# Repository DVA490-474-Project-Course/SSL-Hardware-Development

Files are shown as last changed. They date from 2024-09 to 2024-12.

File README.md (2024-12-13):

# SSL-Hardware-Development

## Overview
Welcome to the SSL Robot Project repository! This project encompasses both hardware and software components essential for building and controlling an SSL robot. Our goal is to create a robust, scalable, and maintainable robot platform.

## Repository Structure
- **3D_Models**: Contains all 3D models related to the robot design.
- **Circuits**: Circuit designs for various robot components.
- **BOM**: Bill of Materials for each component.
- **Software**: Firmware and software for motor control and other functionalities.
- **Design_Documents**: Technical specifications and design decisions.
- **Meeting_Notes**: Documentation of project meetings.
- **Misc**: Miscellaneous files and references.
- **Simulations**: Simulation scripts and models.
- **Documentation**: Comprehensive project documentation and guides.

```bash
/SSL-Robot-Project
├── /3D_Models
│   ├── /CAD_Files            # All CAD files for different robot parts
│   ├── /STL_Files            # STL exports for 3D printing
│   └── /Renderings           # Renders of the 3D models
├── /Circuits
│   ├── /Motor_Control        # Motor circuit design files
│   ├── /Kicker               # Kicker circuit design files
│   ├── /Dribbler             # Dribbler circuit design files
│   └── /Sensor               # Sensor circuit design files
├── /BOM                      # Bill of Materials for different components
├── /Software
│   ├── /Motor_Control
│   │   ├── /Firmware          # Firmware code for motor controllers
│   │   │   ├── /src           # Source code files
│   │   │   ├── /include       # Header files
│   │   │   ├── /tests         # Unit and integration tests
│   │   │   └── README.md      # Firmware-specific documentation
│   │   ├── /Software_Doc      # Documentation related to motor control software
│   │   │   ├── /API_Docs      # API documentation if applicable
│   │   │   └── /User_Guides   # User manuals or setup guides
│   │   ├── /Libraries         # Any libraries or dependencies specific to motor control
│   │   └── /Examples          # Example projects or usage scenarios
│   ├── /Kicker_Control        # Similar structure for kicker control software
│   ├── /Dribbler_Control      # Similar structure for dribbler control software
│   └── /Sensor_Control        # Similar structure for sensor control software
├── /Design_Documents          # Technical specifications, design decisions
├── /Meeting_Notes             # Notes from each project meeting
├── /Misc                      # Any other miscellaneous files
├── /Simulations               # Simulation files or scripts if applicable
├── /Documentation             # General documentation for the project
│   ├── README.md              # Overview of the project
│   ├── CONTRIBUTING.md        # Guidelines for contributing
│   ├── LICENSE.md             # Licensing information
│   └── /Wiki_Links            # Links to relevant wiki pages
└── .gitignore                 # Git ignore file
```

## Getting Started

### Prerequisites
- **Hardware**: Access to the necessary hardware components as listed in the BOM.
- **Software**: Install required software dependencies (refer to [Dependencies](Software/Software_Dependencies.md) documentation).

### Setup Instructions
1. **Clone the Repository**
    ```bash
    git clone git@github.com:DVA490-474-Project-Course/SSL-Hardware-Development.git
    cd SSL-Robot-Project
    ```

2. **Setup Software Environment**
    - Navigate to the software directory:
        ```bash
        cd Software/Motor_Control
        ```
    - Follow the instructions in `README.md` to build and deploy the firmware.

3. **Accessing Documentation**
    - Visit the [Wiki](https://github.com/DVA490-474-Project-Course/SSL-Hardware-Development/wiki) for detailed guides and API documentation.

## Contributing
We welcome contributions! Please read our [CONTRIBUTING.md](Documentation/CONTRIBUTING.md) for guidelines on how to get involved.

## License
This project is licensed under the [MIT License](Documentation/LICENSE).

## Contact
For any questions or support, please open an issue or contact the project maintainers.

Pontus Svensson - psn19003@student.mdu.se

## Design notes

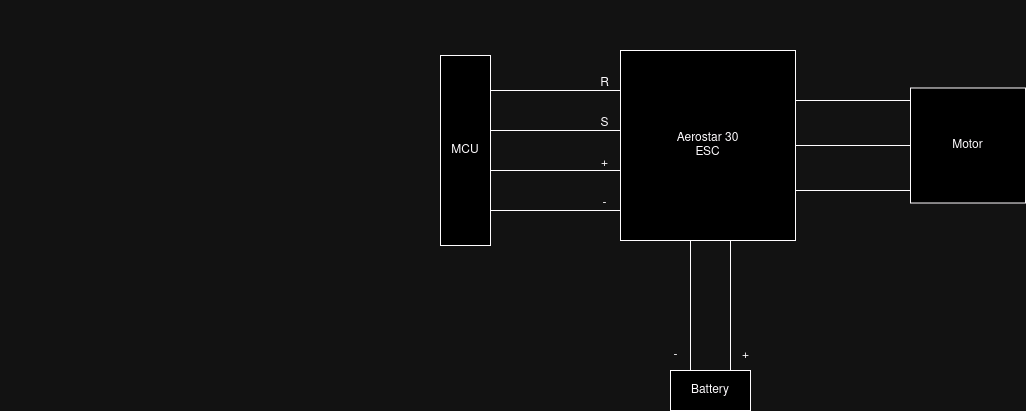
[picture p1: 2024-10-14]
Design_Documents/Dribbler/Aerostar_dribbler_diagram.png

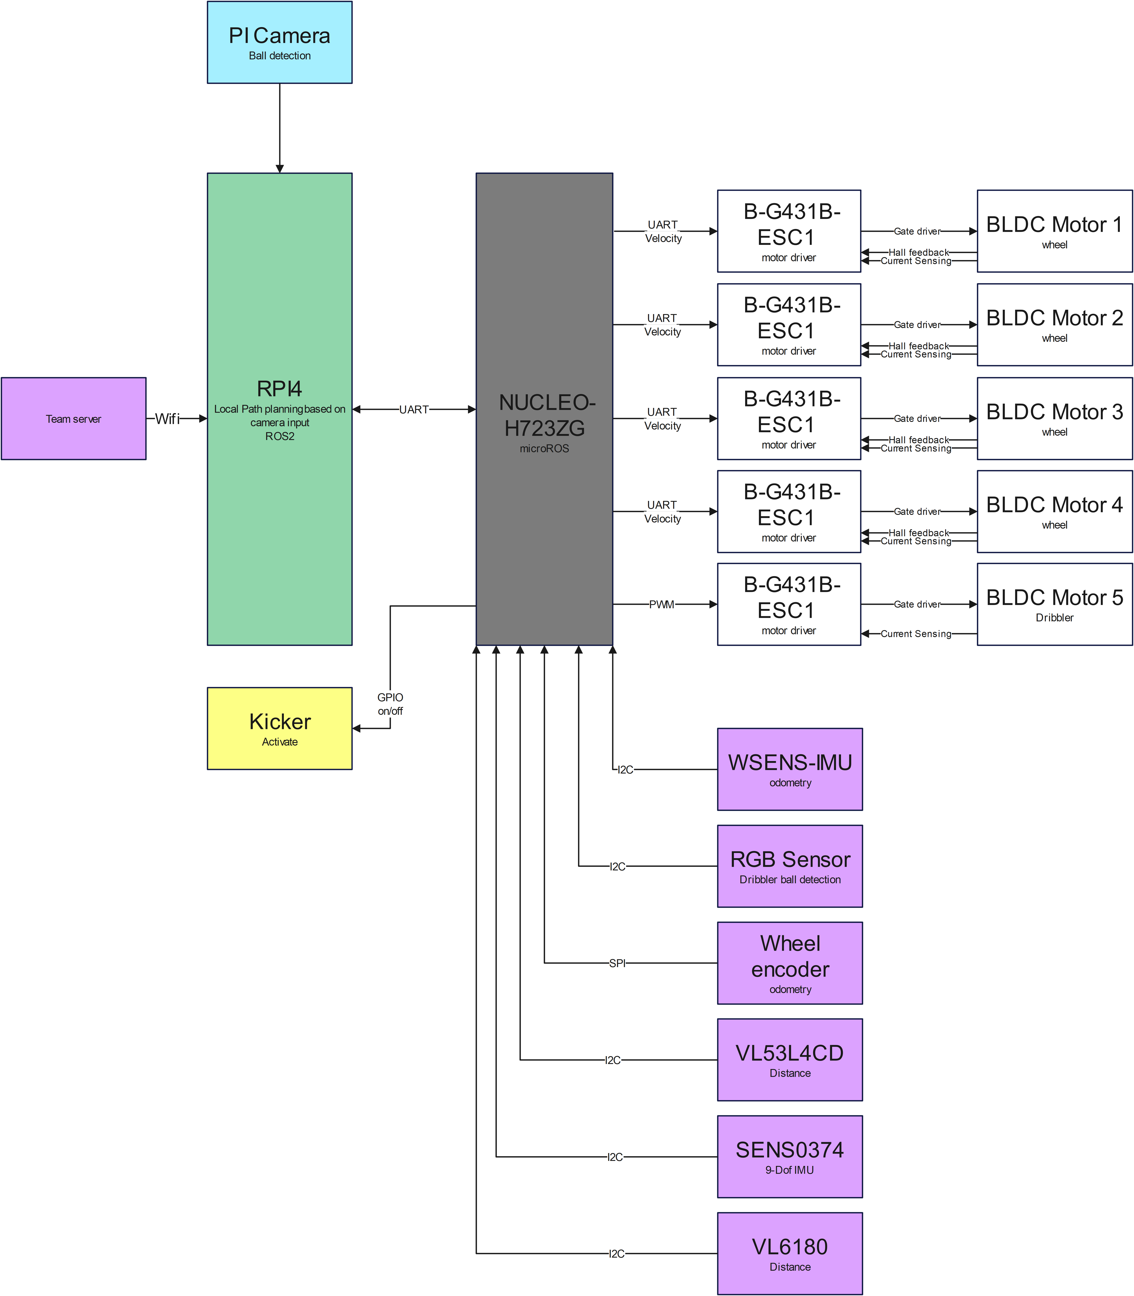
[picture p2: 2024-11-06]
Design_Documents/Architecture/Hardware_architecture.png

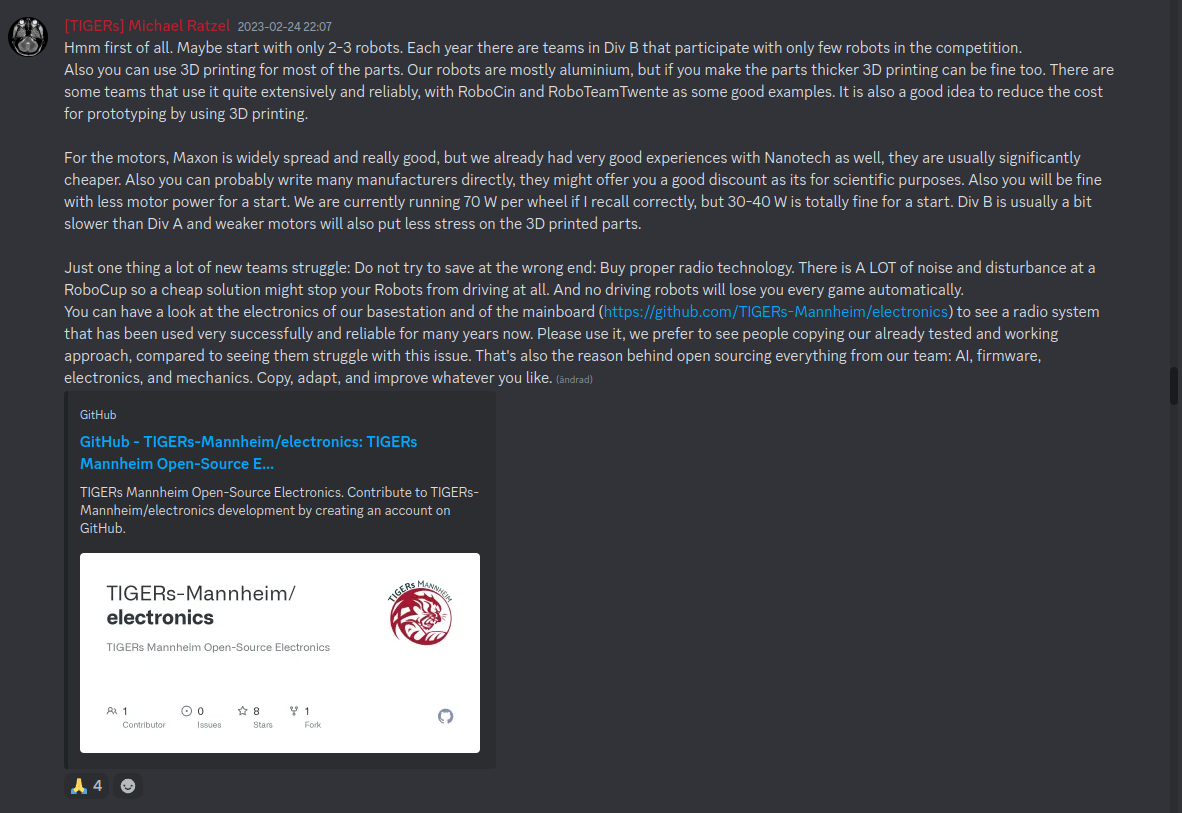
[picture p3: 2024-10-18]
Misc/knwoledge_from_tigers.png

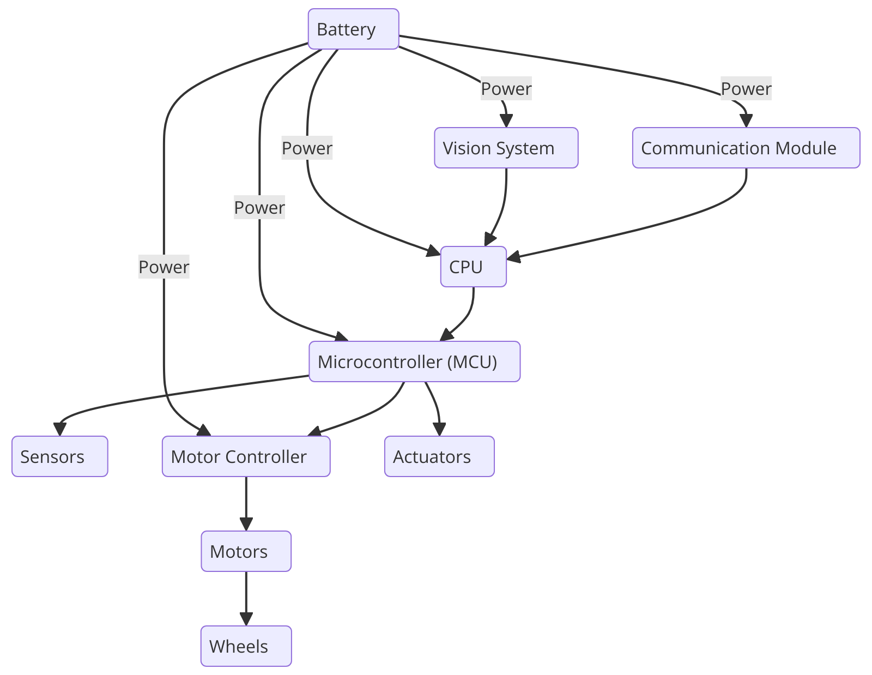
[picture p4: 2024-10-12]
Misc/diagram.png

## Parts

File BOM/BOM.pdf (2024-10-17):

BOM

Part name | Quantity
DF45L024048-A – Brushless DC motor | 4
Hobbywing FPV XRotor 3110 900KV | 1
6s 1300mAh -120C - GNB HV XT60 | 1
M3 16mm galvanized steel countersunk screw, 100 pack | 1
M3 galvanized steel locking washers, 200 pack | 1
M3 steel locking washers, 200 pack | 1
M3 stainless steel nut, 100 pack | 1
PHR-6 | 8
B6B-PH-K-S | 10
VHR-5N | 10
Bearings with flange iglidur® M250 | 200
X-RING 3.63X2.62/NBR70 | 100
SEN0374 | 1
Raspberry Pi RTC | 1
| 2
LM74500QDDFRQ1 | 2
BUK9Y8R5-80EX | 2
NUCLEO-H723ZG | 1
SX1280IMLTRT | 1
SKY66122-11 | 1
B-G431B-ESC1 | 5
Wheel hub 4mm | 4
Raspberry Pi 4 Model B/8GB | 1
Raspberry Pi Kameramodul 3 | 1
Bearings 5mm | 6
M3 threaded inserts 3mm, 50 pack | 1
APDS-9960 | 1
TOF400C-VL53L1 | 1
VL6180 TOF | 1
XT60PW-M | 1
2-post pillow block, 32mm bore | 4
B5P-VH | 10
OFFERT finns för nedanstående, se bifogad fil
OFFERT – BROADCOM AEDB-9140-A13 | 8

LT3751

Distributor

https://www.nanotec.com/eu/en/products/1786-df45l024048-a
https://www.elefun.se/p/prod.aspx?v=65193
https://www.elefun.se/p/prod.aspx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
https://www.elfa.se/sv/lasbricka-m3-stal-bossard-az-2x6x0-cll4880/p/30071831https://www.elfa.se/sv/sexkantsmutter-m3-4mm-rostfritt-stal-rnd-rnd-610-00485/p/30172720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

https://www.mouser.se/ProductDetail/Analog-Devices/LT3751IFEPBF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

https://www.mouser.se/ProductDetail/511-NUCLEO-H723ZGhttps://www.mouser.se/ProductDetail/Semtech/SX1280IMLTRT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
https://www.electrokit.com/axelnav-med-klamfaste-4mm
https://www.electrokit.com/raspberry-pi-4-model-b/8gb
https://www.electrokit.com/raspberry-pi-kameramodul-3-12mp-75https://www.electrokit.com/kullager-5mmhttps://www.electrokit.com/ganginsats-m3-x-3mm-50-packhttps://www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

https://uk.farnell.com/broadcom-limited/aedb-9140-a13/encoder-3channel-500cpr-8mm/dp/1161087

Distributor Part Number

DF45L024048-A
65193
63197
301-72-632
300-71-826
300-71-831
301-72-720
143-01-984
143-01-948
300-21-738
MFM-0103-02
2111395N70
426-SEN0374
713-103030277

584-LT3751IFE#PBF
595-LM74500QDDFRQ1
771-BUK9Y8R5-80EX

511-NUCLEO-H723ZG
947-SX1280IMLTRT
873-SKY66122-11
511-B-G431B-ESC1
41020172
41017664 - Raspberry Pi
41020240 - Raspberry Pi
41019266
41018554
41013512 – Sparkfun

XT60PW-M
RP-Sct-2151
JST (JAPAN SOLDERLESS TERMINALS) B5P-VH(LF)(SN)

BROADCOM AEDB-9140-A13

Manufacturer | Mfr Part number | Á price
| | 818.4
https://www.hobbywing.com/ | HW30418005 | 219
http://www.gaonengbattery.com/ | GNB13006S120AHV | 442
https://www.elfa.se/sv/manufacturer/rnd/man_rnd | RND 610-00397 | 21.6
https://www.bossard.com/se-sv/ | AZ 3,2X6X0,4 | 69.7
https://www.bossard.com/se-sv/ | AZ S 3,2X6X0,4 / CLL4880 S | 83.3
https://www.elfa.se/sv/manufacturer/rnd/man_rnd | RND 610-00485 | 21.85
https://www.elfa.se/sv/manufacturer/jst/man_jst | PHR-6 | 1.07
https://www.elfa.se/sv/manufacturer/jst/man_jst | B6B-PH-K-S | 5.43
https://www.elfa.se/sv/manufacturer/jst/man_jst | VHR-5N | 2.22
https://www.igusab.se/ | MFM-0103-02 | 3.34
| | 6.2
https://www.mouser.se/manufacturer/dfrobot/ | SEN0374 | 191.48
https://www.mouser.se/manufacturer/seeed-studio/ | 103030277 | 1
https://www.mouser.se/manufacturer/analog-devices/ | LT3751IFE#PBF | 147.09
https://www.mouser.se/manufacturer/texas-instruments/ | LM74500QDDFRQ1 | 16.45
https://www.mouser.se/manufacturer/nexperia/ | BUK9Y8R5-80EX | 17.94
https://www.mouser.se/manufacturer/stmicroelectronics/ | NUCLEO-H723ZG | 322.58
https://www.mouser.se/manufacturer/semtech/ | SX1280IMLTRT | 75.44
https://www.mouser.se/manufacturer/skyworks-solutions/ | SKY66122-11 | 40.48
https://www.mouser.se/manufacturer/stmicroelectronics/ | B-G431B-ESC1 | 208.96
https://www.gobilda.com/ | 1309-0016-0004 | 139
https://www.raspberrypi.com/ | | 979
https://www.raspberrypi.com/ | | 369
| | 15
| | 95
https://www.sparkfun.com/ | APDS-9960 | 199
https://www.mouser.se/manufacturer/stmicroelectronics/ | VL53L1CBV0FY/1 | 176.32
https://www.st.com/en/imaging-and-photonics-solutions/vl6180.html VL6180 | 33
https://www.tme.eu/se/katalog/p,amass_1260/ | XT60PW-M | 11.21
https://www.servocity.com/ | 1602-0032 | 172.29
https://se.farnell.com/b/jst-japan-solderless-terminals | B5P-VH(LF)(SN) | 5.21
https://uk.farnell.com/b/broadcom | AEDB-9140-A13 | 309

1 Robot Cost Lead time | Notes

3273.6 In stock
219 In stock | BLDC motor for the dribbler
442 In stock | Battery
21.6 In stock
69.7 In stock
83.3 In stock
21.85 In stock
8.56 In stock | Hall sensor connector for the motor
54.3 In stock | Hall sensor connector for the motor
22.2 In stock | Motor connectors
334 in stock | Price dependent on the amount you buy
620 in stock | Price dependent on the amount you buy
191.48 4 left in stock | 9Dof IMU
47.61 In stock

294.18 In stock
32.9 In stock | Reverse polarity protection
35.88 In stock | Mosfet used with the reverse polarity protection component

322.58 In stock
75.44 In stock | RF Transceiver Long range 2.4 GHz Wireless Transceiver
40.48 In stock | RF Front End OFDM, 863 to 928 MHz, Wi-SUN, FEM
1044.8 In stock | Datasheet
556 in stock
979 In stock | Can be substituted with Raspberry Pi 4 Model B/4GB
369 In stock | Needs to be ordered with Raspberry Pi 4 Model B/8GB or Raspberry Pi 4 Model B/4GB
90 In stock | for dribbler assembly.
95 In stock
199 In stock | Chosen by UdeA, RGB sensor
176.32 In stock | Chosen by UdeA, could not find from another seller
33 In stock | Chosen by UdeA, could not find from another seller
11.21 In stock | XT60 PCB connector
689.16 On demand, 1 month delivery time For extra support for the wheels, compatible with chosen hub.
52.1 In stock | Motor connectors
2472 In stock | Offert från farnell med studentrabatt
12977.25

BLDC motors for the wheels, compact size, light weight, contains hall sensors for encoder feedback Sensored ESC is required if these are used

Capacitor charging controller for kicker

If we do not develop our own pcb this microcontroller can be used instead of the ESP32 microcontroll-Er, ADC, communication, supports micro ros

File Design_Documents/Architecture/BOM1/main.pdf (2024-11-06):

Table 1: Main components

Component | Description | Purpose | # | ´a price (price per robot) SEK | Price in USD
DF45L024048-A (https://www.nanotec.com/fileadmin/files/Datenblaetter/BLDC/DF45/DF45L024048-A.pdf?1656012533) | Brushless direct current (BLDC) motor with inte-grated hall sensors for the wheels | Used to spin the wheels of the robot. | 4 | 830.4 (3273.60) | 74.74 (294.6)
Hobbywing FPV XRotor 3110 900KV (https://www.hobbywing.com/en/products/xrotor3110) | Brushless DC mo-tor | High revolutions per minute (RPM) motor used to con-trol the dribbler. | 1 | 175.20 (175.20) | 15.77 (15.77)
B-G431B-ESC1 (https://www.mouser.se/datasheet/2/389/b-g431b-esc1-1848063.pdf) | BLDC motor driver | Motor driver with embedded µController current sensing and hall sensing to form a closed-loop control algorithm | 5 | 208.96 (1044.8) | 18.8 (94.032)
NUCLEO-H723ZG (https://www.st.com/en/evaluation-tools/nucleo-h723zg.html) | µController | Computational power and real-time processing capabilities, sup-ports µROS | 1 | 322.58 (322.58) | 29 (29)
Raspberry Pi 4 Model B/8GB (https://datasheets.raspberrypi.com/rpi4/raspberry-pi-4-datasheet.pdf) | Single-board com-puter | Processing camera input and perform-ing local path plan-ning | 1 | 979 (979) | 88.11 (88.11)
VL53L4CD ToF (https://learn.adafruit.com/adafruit-vl53l4cd-time-of-flight-distance-sensor?view=all) | Lidar | Obstacle detection (Could not find VL53X ToF) | 2 | 176.32 (176.32) | 15.87 (15.87)
VL6180 TOF (https://www.electrokit.com/upload/product/41013/41013634/DM00112632.pdf) | Lidar | Obstacle detection | 1 | 39.62 (39.62) | 3.57 (3.57)
APDS-9960 (https://docs.broadcom.com/doc/AV02-4191EN) | RGB Sensor | Ball detection | 1 | 199 (199) | 17.91 (17.91)
SENS0374 (https://wiki.dfrobot.com/BNO055_Intelligent_9_Axis_Sensor_Module_SKU_SEN0374) | 9-Dof IMU | Acceleration, Gyro-scope, Magnetome-ter | 1 | 191 (191) | 17.19 (17.19)
6s 1300mAh -120C - GNB HV XT60 (https://www.elefun.se/p/prod.aspx?v=65193) | LiPo-battery | Used to power the robot | 1 | 351.20 (351.20) | 31.6 (31.6)
iC-PX2604 + PX01S 26-30 (https://www.ichaus.de/product/ic-px-series/#documents) | Wheel encoders | Will be used for odometry and de-termining the RPM | 4 | 224.40 (897.60) | 20.2 (80.78)
WSEN-ISDS 6 Axis IMU (https://www.we-online.com/components/products/datasheet/2536030320001.pdf) | 6-DoF IMU | Will be used for odometry of the robot | 10 | N/A | N/A
Raspberry Pi Camera-module 3 (https://www.electrokit.com/upload/product/41020/41020240/Camera_Module_3_Product_Brief.pdf) | Camera | Provide images in front of the robot to detect the ball and obstacles | 1 | 369 (369) | 33.21 (33.21)

1

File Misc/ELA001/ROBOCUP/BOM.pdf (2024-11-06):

# Bill of Materials (BOM) Explanation

Pontus Svensson / RoboCup

November 6, 2024

## Contents

1 Introduction | 3
2 BOM | 3
3 Reason for component choice | 4
4 Hardware Architecture | 6

## 1 Introduction

This document provides an explanation of the Bill of Materials (BOM) used in the project. Each component listed in the BOM is described in detail, including its purpose and other relevant specifications.

## 2 BOM

Table 1 below outlines the components used in this project along with their purpose and additional information.

Table 1: Main components

Component | Description | Purpose | # | ´a price (price per robot) SEK | Price in USD
DF45L024048-A (https://www.nanotec.com/fileadmin/files/Datenblaetter/BLDC/DF45/DF45L024048-A.pdf?1656012533) | Brushless direct current (BLDC) motor with inte-grated hall sensors for the wheels | Used to spin the wheels of the robot. | 4 | 830.4 (3273.60) | 74.74 (294.6)
Hobbywing FPV XRotor 3110 900KV (https://www.hobbywing.com/en/products/xrotor3110) | Brushless DC mo-tor | High revolutions per minute (RPM) motor used to con-trol the dribbler. | 1 | 175.20 (175.20) | 15.77 (15.77)
B-G431B-ESC1 (https://www.mouser.se/datasheet/2/389/b-g431b-esc1-1848063.pdf) | BLDC motor driver | Motor driver with embedded µController current sensing and hall sensing to form a closed-loop control algorithm | 5 | 208.96 (1044.8) | 18.8 (94.032)
NUCLEO-H723ZG (https://www.st.com/en/evaluation-tools/nucleo-h723zg.html) | µController | Computational power and real-time processing capabilities, sup-ports µROS | 1 | 322.58 (322.58) | 29 (29)
Raspberry Pi 4 Model B/8GB (https://datasheets.raspberrypi.com/rpi4/raspberry-pi-4-datasheet.pdf) | Single-board com-puter | Processing camera input and perform-ing local path plan-ning | 1 | 979 (979) | 88.11 (88.11)
VL53L4CD ToF (https://learn.adafruit.com/adafruit-vl53l4cd-time-of-flight-distance-sensor?view=all) | Lidar | Obstacle detection (Could not find VL53X ToF) | 2 | 176.32 (176.32) | 15.87 (15.87)
VL6180 TOF (https://www.electrokit.com/upload/product/41013/41013634/DM00112632.pdf) | Lidar | Obstacle detection | 1 | 39.62 (39.62) | 3.57 (3.57)
APDS-9960 (https://docs.broadcom.com/doc/AV02-4191EN) | RGB Sensor | Ball detection | 1 | 199 (199) | 17.91 (17.91)
SENS0374 (https://wiki.dfrobot.com/BNO055_Intelligent_9_Axis_Sensor_Module_SKU_SEN0374) | 9-Dof IMU | Acceleration, Gyro-scope, Magnetome-ter | 1 | 191 (191) | 17.19 (17.19)
6s 1300mAh -120C - GNB HV XT60 (https://www.elefun.se/p/prod.aspx?v=65193) | LiPo-battery | Used to power the robot | 1 | 351.20 (351.20) | 31.6 (31.6)
iC-PX2604 + PX01S 26-30 (https://www.ichaus.de/product/ic-px-series/#documents) | Wheel encoders | Will be used for odometry and de-termining the RPM | 4 | 224.40 (897.60) | 20.2 (80.78)
WSEN-ISDS 6 Axis IMU (https://www.we-online.com/components/products/datasheet/2536030320001.pdf) | 6-DoF IMU | Will be used for odometry of the robot | 10 | N/A | N/A
Raspberry Pi Camera-module 3 (https://www.electrokit.com/upload/product/41020/41020240/Camera_Module_3_Product_Brief.pdf) | Camera | Provide images in front of the robot to detect the ball and obstacles | 1 | 369 (369) | 33.21 (33.21)

## 3 Reason for component choice

### 3.1 DF45L024048-A

During competition a SSL-robot is most of the time accelerating [1]. Having a motor which can provide sufficient torque at any given speed is crucial.
The DF45L024048-A BLDC motors provides a good tradeoff between torque and RPM, with integrated hall sensors. The sensors detect the position of the rotor relative to the stator which gives the ability to control the motors using commutation. The motor controller uses the signals from the hall sensors to determine the exact timing for switching the current in the stator windings. This gives a smooth motor operation while maximizing torque output.
The size of the motor has to be taken into account. Having to large footprint on the motors would cause the kicker (solenoid) to not fit in the chassi. Using a general 5010 sensorless drone motor could be used as demonstrated by [2] but this motor would require a more sophisticated ESC which would take a lot of time to develop and manufacture. The problem with searching for 5010 drone motors is that most websites does not show the full torque graph, they primarly show the torque when the motor is already spinning at 40% throttle and above. Therefore finding a 5010 drone motor with adequate torque at low speeds is deceptively difficult.
Using hall sensors is a common method utilized by several teams and proven to be a winning concept [3][4][5][1].

### 3.2 Hobbywing FPV XRotor 3110 900KV

The requirements for the dribbler motor is that it can reach high RPM (around 10000 RPM). No feedback is implemented for the dribbler motor, due to the timeframe of the project a control algorithm will not be implemented.

### 3.3 B-G431B-ESC1

A sensorless controller requires that the BLDC motor produce a measurable back electromotive force (EMF) so the controller can determine the position of the rotor and therefore cannot provide smooth commutation at start up and low speeds. [6]
The chosen electronics speed controller (ESC) has an STSPIN32F0A system in package chip which has an integrated STM32 processor with hall sensor decoding logic and current sensing capabilities. This makes this ESC a good fit with the DF45L024048-A BLDC motor.
The STSPIN32F0A chip is a common choice for controlling BLDC motors in the SSL competitions which has been proven to be reliable and succesful [3][7].
Field-Oriented control (FOC) can be implemented on the B-G431B-ESC1. Guidance and firmware for the B-G431B-ESC1 has been received from Delft Mercurians that will make the process of implementing this streamlined.
A PID system can be implemented on the chip to allow for precise movement and rapid acceleration which is critical to make fast directions changes.
The B-G431B-ESC1 will receive a desired velocity, to use this within a PID system the RPM of each motor is required. The size and weight of the ESC does also have to be taken in consideration, the B-G431B-ESC1 has a small footprint with a relatively low weight 286g. With all the components integrated on one board will make the assembly process easier and reduce any external components e.g. hall sensing or mosfets. The programming for the integrated STM32 is done using STM32 Motor Control Software Development Kit which is a graphical programming environtment from ST.

### 3.4 NUCLEO-H723ZG Microcontroller

The NUCLEO-H723ZG is a development board based on the STM32H723ZG chip, it comes with all necessary peripheral communication UART, SPI, I2C and CAN. The STM32H723ZG features an ARM Cortex-M7 core operating at up to 480 MHz, providing good processing power for handling multiple real-time tasks required in our application. Additionally, the STM32 series is widely adopted in RoboCup competitions, including the Small Size League (SSL) [3][8][5]. This widespread use underscores its reliability and effectiveness in competititions. By using STM32H723ZG chip, previous teams implementations that is open sourced can be used for guidance when developing.
To manage the various tasks and ensure smooth operation of our robot, the control architecture will be implemeted using micro-ROS in combination with FreeRTOS on the NUCLEO-H723ZG.
FreeRTOS is a real-time operating system that provides task scheduling and resource management. Implementing FreeRTOS on the NUCLEO-H723ZG allows us to handle multiple concurrent tasks efficiently, such as sensor data processing, motor control, and communication with other system components.
By using the STM32H723ZG chip future improvements can be made, without having to replace the hardware and potentially the need to re-program/port using another framework.

### 3.5 Raspberry Pi 4 Model B/8GB

It is important to accurately detect the ball and other robots in a timely manner, therefore a Raspberry Pi camera will be used, and the input image will be processed on the Raspberry Pi 4. The Raspberry pi has been used in the SSL competitions for this purpose [9][10]. A lot of information and open sourced firmware exist.

The Raspberry Pi 4 was also chosen to be able to run the DWA path planning algorithm, due to the timeframe of this project, implementing DWA by ourself would require too much time.

### 3.6 VL53L4CD ToF Sensor

The VL53L4CD ToF (Time-of-Flight) sensor is a laser-based ranging sensor capable of measuring distances with high accuracy. It is used for obstacle detection in the robot, allowing the system to identify obstacles within close proximity. With a range of up to 1300 mm, it is especially suited for detecting obstacles that could interfere with the robot’s navigation. The sensor communicates using I2C, which simplifies integration with the existing hardware.

### 3.7 VL6180 TOF Sensor

The VL6180 TOF sensor, also a Time-of-Flight sensor, serves a similar purpose as the VL53L4CD but operates at shorter distances, making it ideal for near-field obstacle detection. It is also chosen for its compact size and I2C communication, which allows it to seamlessly interface with the microcontroller. The shorter range provides additional resolution for objects very close to the robot, further enhancing obstacle detection accuracy.

### 3.8 APDS-9960 Sensor

The APDS-9960 sensor is a versatile RGB sensor with integrated IR sensing capabilities. It is primarily used in this project for ball detection, as it can distinguish colors and detect the presence of nearby objects. This feature enables the robot to differentiate the ball from the surroundings based on color and proximity. Communication is handled via I2C, allowing for easy connection to the system’s microcontroller.

### 3.9 SENS0374 Sensor

The SENS0374, based on the Bosch BNO055 sensor, is a 9-axis absolute orientation sensor module. It integrates a triaxial accelerometer, gyroscope, and geomagnetic sensor with a 32-bit microcontroller, providing orientation data essential for stable navigation and localization. The module includes an onboard fusion algorithm that combines sensor readings to deliver absolute orientation, minimizing drift over time. The SENS0374 communicates via I2C and SPI, making it flexible for integration with the main controller. This sensor will aid in tracking the robots movement, orientation, and any external forces acting upon it, enhancing its responsiveness in dynamic environments.

### 3.10 SX1280IMLTRT + SKY66122-11

To obtain a reliable connection to the team server, the SX1280IMLTRT RF transceiver with the SKY66122-11 front-endmodule is used.
This implementation has been proven succesful by several teams [3][11].
However, to implement this, a basestation is required and due to the time limitation of this project it is not feasible to design and write firmware for our own network protocol, but these components will be added to the mainboard PCB for future iterations. The communication will instead be done using the wifi on the Raspberry Pi 4.

### 3.11 iC-PX2604 + PX01S 26-30

This wheel encoder comes as a complete module which will be easy to integrate and in combination with the NUCLEO-H723ZG the resolution of the encoder is increased.
Optical wheel encoders is commonly used by teams competing in the SSL competitions.

### 3.12 WSEN-ISDS 6 Axis IMU

The IMU chosen is supplied free of charge from W¨urth electronics. It communicates using I2C or SPI which both are available on the NUCLEO-H723ZG.

### 3.13 Raspberry Pi Camera-module 3

The Raspberry Pi camera-module 3 is chosen because of its seamless integration with the Raspberry Pi 4.
A custom made solenoid would be preferred, but due to time a generic solenoid will be used for starting car engines. Supplied by MDU.

### 3.14 PCB

As some of our components require a custom PCB, three PCBs will be designed. A mainboard, kicker-board and encoder board, the main board will host connectors for the battery, motors, sensors, NUCLEO-H723ZG and pin headers for powering the Raspberry Pi. The mainboard will also host the RF transceiver, IMU and voltage regulators.

## 4 Hardware Architecture

Figure 1 depicting the hardware architecture of the proposed robot.

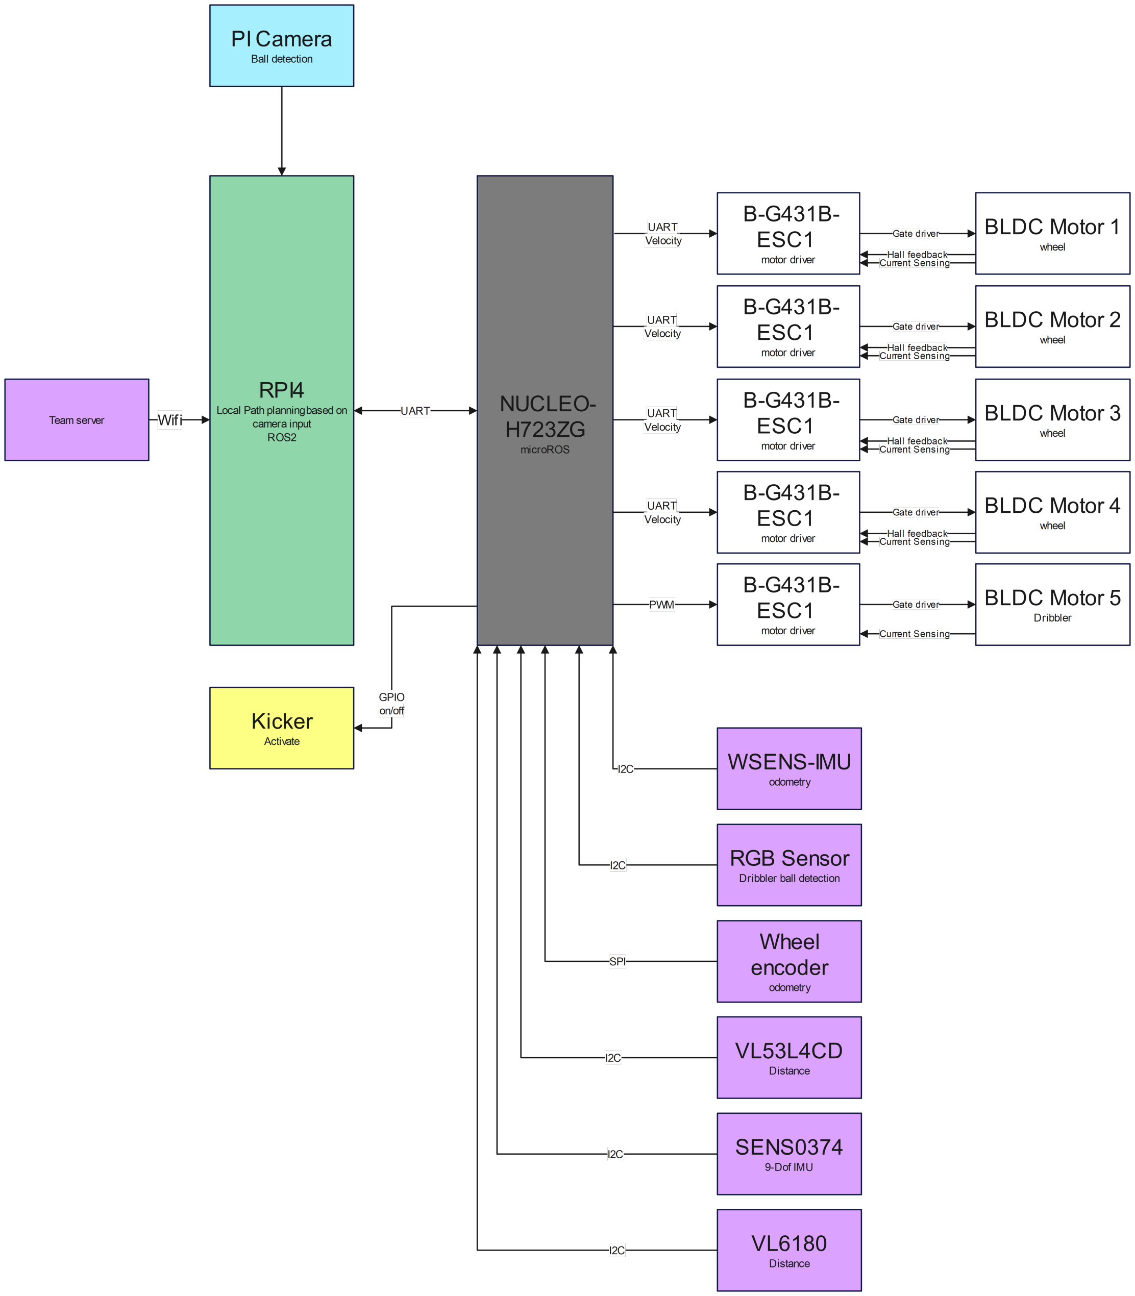
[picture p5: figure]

Figure 1: Hardware Architecture

## References

[1] A. Franca, B. Barros, C. Gomes, C. Silva, C. M. Alves, D. C. Barbosa, D. Xavier, E. Araujo, F. Pereira, L. H. Cavalcanti, M. Asfora, M. Alves, M. Paixao, M. Vasconcelos, M. Vinıcius, J. G. Melo, J. R. Silva, J. Leite, P. H. Santana, P. P. Oliveira, R. Rodrigues, T. Teobaldo, V. Dutra, V. Araujo, and E. Barros, “RobˆoCIn Small Size League Extended Team Description Paper for RoboCup 2024.”
[2] A. Veeraghanta, H. Bryant, S. Zheng, M. MacDougall, S. Guido, and L. Bontkes, “2024 Team Description Paper: The Bots.”
[3] A. Ryll and S. Jut, “Extended Team Description for RoboCup 2020.”
[4] D. R. H. Abiyev, N. Akkaya, T. Yirtici, E. Aytac, G. Burge, S. Abizada, A. Turk, and G. Say, “NEUIslanders Team Description Paper RoboCup 2022.”
[5] Y. Wu, K. Liu, J. Fan, H. Zhang, J. L. Minghe, Q. Li, and J. Li, “Compilation Error Team Description Paper for Small Size League of Robocup 2024.”
[6] A. Rowe, G. Sen Gupta, and S. Demidenko, “Instrumentation and control of a high power BLDC motor for small vehicle applications,” in 2012 IEEE International Instrumentation and Measurement Technology Conference Proceedings. Graz, Austria: IEEE, May 2012, pp. 559–564.
[7] A. Abousaleh, A. Balamurali, B. Blair, R. Cao, M. Charara, L. Chee, J. Coffin, J. Guo, W. Ha, F. Haas, T. Kong,
R. Khan, C. Lee, O. Levy, R. Nedjabat, M. Phung, A. Sidhu, D. Sturn, M. Tong, B. Vasilchikov, K. Wakaba,
N. Zareian, S. Banna, P. Zhou, and Y. B. Zhou, “2024 Team Description Paper: UBC Thunderbots.”
[8] A. Zhao, P. Yu, Z. Huang, N. Shen, J. Yang, J. Yu, Z. Chen, L. Wang, and R. Xiong, “ZJUNlict Extended Team Description Paper.”
[9] N. Ommer, A. Ryll, M. Ratzel, and M. Geiger, “Extended Team Description for RoboCup 2024.”
[10] H. Sato, N. Okamoto, A. Ito, S. Kayaki, T. Nakao, Y. Nishimura, Y. Hara, and R. Yuri, “GreenTea 2024 Team Description Paper.”
[11] H. Barreto, L. E. Horie, E. G. Frese, de Freitas, M. C. Antunes, E. Baldi, and E. H. V. Melo, “RoboIME: Igniting Innovation, Shaping the Future in RoboCup 2024.”

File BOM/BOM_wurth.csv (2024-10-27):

Order code | Quantity | Description | Link
885012007063 | 10 | WCAP-CSGP MLCCs 50 V(DC) 1nF 0805 | https://www.we-online.com/en/components/products/WCAP-CSGP-50VDC#885012007063
885012207092 | 10 | WCAP-CSGP MLCCs 50 V(DC) 10nF 0805 | https://www.we-online.com/en/components/products/WCAP-CSGP-50VDC#885012207092
885012207098 | 12 | WCAP-CSGP MLCCs 50 V(DC) 0.1uF 0805 | https://www.we-online.com/en/components/products/WCAP-CSGP-50VDC?sq=885012207098#885012207098
885012207103 | 10 | WCAP-CSGP MLCCs 50 V(DC) 1uF 0805 | https://www.we-online.com/en/components/products/WCAP-CSGP-50VDC#885012207103
885012107018 | 1 | WCAP-CSGP MLCCs 50 V(DC) 4.7uF 0805 | https://www.we-online.com/en/components/products/WCAP-CSGP-25VDC#885012107018
885012209073 | 10 | WCAP-CSGP MLCCs 50 V(DC) 10uF 1210 | https://www.we-online.com/en/components/products/WCAP-CSGP-50VDC#885012209073
865080657018 | 10 | WCAP-ASLI Aluminum Electrolytic Capacitors 220uF | https://www.we-online.com/en/components/products/WCAP-ASLI#865080657018
865060663013 | 5 | WCAP-ASLI Aluminum Electrolytic Capacitors 470uF | https://www.we-online.com/en/components/products/WCAP-ASLL#865060663013
61301621821 | 1 | Socket Header Dual 16 Pins 2.54 mm | https://www.we-online.com/en/components/products/PHD_2_54_DUAL_SOCKET_HEADER_6130XX21821#61301621821
61303021821 | 1 | Socket Header Dual 30 Pins 2.54 mm | https://www.we-online.com/en/components/products/PHD_2_54_DUAL_SOCKET_HEADER_6130XX21821#61303021821
61302021821 | 1 | Socket Header Dual 20 Pins 2.54 mm | https://www.we-online.com/en/components/products/PHD_2_54_DUAL_SOCKET_HEADER_6130XX21821#61302021821
61303421821 | 1 | Socket Header Dual 32 Pins 2.54 mm | https://www.we-online.com/en/components/products/PHD_2_54_DUAL_SOCKET_HEADER_6130XX21821#61303421821
61307221821 | 2 | Socket Header Dual 72 Pins 2.54 mm | https://www.we-online.com/en/components/products/PHD_2_54_DUAL_SOCKET_HEADER_6130XX21821?sq=61307221821
61307221121 | 2 | Pin Header Dual 72 Pins 2.54 mm | https://www.we-online.com/en/components/products/PHD_2_54_THT_DUAL_PIN_HEADER_6130XX21121
61304011121 | 1 | Pin Header Single 40 Pins 2.54 mm | https://www.we-online.com/en/components/products/PHD_2_54_THT_PIN_HEADER_6130XX11121#61304011121
61300211821 | 2 | Socket Header Single 2 Pins 2.54 mm | https://www.we-online.com/en/components/products/PHD_2_54_SOCKET_HEADER_6130XX11821#61300211821
560112120001 | 4 | Resistor 10Ohm 0805 | https://www.we-online.com/en/components/products/WRIS-RSKS?sq=560112120001#560112120001
560112120013 | 1 | Resistor 100kOhm 0805 | https://www.we-online.com/en/components/products/WRIS-RSKS#560112120013

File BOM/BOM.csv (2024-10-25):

Part name | Quantity | Distributor | Distributor Part Number | Manufacturer | Mfr Part number | Á price | 1 Robot Cost | Lead time | Notes
DF45L024048-A – Brushless DC motor | 4 | https://www.nanotec.com/eu/en/products/1786-df45l024048-a | DF45L024048-A |  |  | 818.4 | 3273.6 | In stock | BLDC motors for the wheels, compact size, light weight, contains hall sensors for encoder feedback Sensored ESC is required if these are used
Hobbywing FPV XRotor 3110 900KV | 1 | https://www.elefun.se/p/prod.aspx?v=65193 | 65193 | https://www.hobbywing.com/ | HW30418005 | 219 | 219 | In stock | BLDC motor for the dribbler
6s 1300mAh -120C - GNB HV XT60 | 1 | https://www.elefun.se/p/prod.aspx?v=63197 | 63197 | http://www.gaonengbattery.com/ | GNB13006S120AHV | 442 | 442 | In stock | Battery
M3 16mm galvanized steel countersunk screw, 100 pack | 1 | https://www.elfa.se/sv/foersaenkt-skruv-foersaenkt-huvud-torx-t10-m3-16mm-paket-med-100-delar-rnd-rnd-610-00397/p/30172632 | 301-72-632 | https://www.elfa.se/sv/manufacturer/rnd/man_rnd | RND 610-00397 | 21.6 | 21.6 | In stock
M3 galvanized steel locking washers, 200 pack | 1 | https://www.elfa.se/sv/lasbricka-m3-foerzinkat-stal-bossard-az-2x6x0/p/30071826 | 300-71-826 | https://www.bossard.com/se-sv/ | AZ 3,2X6X0,4 | 69.7 | 69.7 | In stock
M3 stainless steel nut, 100 pack | 1 | https://www.elfa.se/sv/sexkantsmutter-m3-4mm-rostfritt-stal-rnd-rnd-610-00485/p/30172720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 | 301-72-720 | https://www.elfa.se/sv/manufacturer/rnd/man_rnd | RND 610-00485 | 21.85 | 21.85 | In stock
PHR-6 | 8 | https://www.elfa.se/sv/hylskontakthus-crimpanslutning-uttag-sockel-positioner-2mm-jst-phr/p/14301984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 | 143-01-984 | https://www.elfa.se/sv/manufacturer/jst/man_jst | PHR-6 | 1.07 | 8.56 | In stock | Hall sensor connector for the motor
B6B-PH-K-S | 10 | https://www.elfa.se/sv/stiftlist-enradig-rak-6p-kontaktdon-anslutningsdon-positioner-2mm-jst-b6b-ph/p/14301948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 | 143-01-948 | https://www.elfa.se/sv/manufacturer/jst/man_jst | B6B-PH-K-S | 5.43 | 54.3 | In stock | Hall sensor connector for the motor
VHR-5N | 10 | https://www.elfa.se/sv/crimp-kontakthus-uttag-sockel-positioner-96mm-jst-vhr-5n/p/30021738 | 300-21-738 | https://www.elfa.se/sv/manufacturer/jst/man_jst | VHR-5N | 2.22 | 22.2 | In stock | Motor connectors
X-RING 3.63X2.62/NBR70 | 100 | https://webbshop.teknikprodukter.se/x-ring-3-63x2-62-nbr70-2111395n70 | 2111395N70 |  |  | 6.2 | 620 | in stock | Price dependent on the amount you buy
SENS | 1 | https://www.mouser.se/ProductDetail/DFRobot/SEN0374?qs=81r%252BiQLm7BRSXhV57X59YA%3D%3D | 426-SEN0374 | https://www.mouser.se/manufacturer/dfrobot/ | SEN0374 | 191.48 | 191.48 | 4 left in stock | 9Dof IMU
Raspberry Pi RTC | 1 | https://www.mouser.se/ProductDetail/Seeed-Studio/103030277?qs=0lSvoLzn4L8soh3xbH07wQ%3D%3D | 713-103030277 | https://www.mouser.se/manufacturer/seeed-studio/ | 103030277 | 1 | 47.61 | In stock
LT3751 | 2 | https://www.mouser.se/ProductDetail/Analog-Devices/LT3751IFEPBF?qs=hVkxg5c3xu8wGIOCrD9eEw%3D%3D | 584-LT3751IFE#PBF | https://www.mouser.se/manufacturer/analog-devices/ | LT3751IFE#PBF | 147.09 | 294.18 | In stock | Capacitor charging controller for kicker
LM74500QDDFRQ1 | 2 | https://www.mouser.se/ProductDetail/Texas-Instruments/LM74500QDDFRQ1?qs=stqOd1AaK7%252BDaolIEn1S7g%3D%3D | 595-LM74500QDDFRQ1 | https://www.mouser.se/manufacturer/texas-instruments/ | LM74500QDDFRQ1 | 16.45 | 32.9 | In stock | Reverse polarity protection
PSMN6R7-40MLDX | 2 | https://www.mouser.se/ProductDetail/Nexperia/PSMN6R7-40MLDX?qs=XeJtXLiO41T0U8eRNXd8kw%3D%3D | 771-PSMN6R7-40MLDX | https://www.mouser.se/manufacturer/nexperia/ | PSMN6R7-40MLDX | 5.77 | 11.54 | In stock | Mosfet used with the reverse polarity protection component
NUCLEO-H723ZG | 1 | https://www.mouser.se/ProductDetail/511-NUCLEO-H723ZG | 511-NUCLEO-H723ZG | https://www.mouser.se/manufacturer/stmicroelectronics/ | NUCLEO-H723ZG | 322.58 | 322.58 | In stock | If we do not develop our own pcb this microcontroller can be used instead of the ESP32 microcontroll- Er, ADC, communication, supports micro ros
SX1280IMLTRT | 1 | https://www.mouser.se/ProductDetail/Semtech/SX1280IMLTRT?qs=5aG0NVq1C4xuoq8G6ZzdxQ%3D%3D | 947-SX1280IMLTRT | https://www.mouser.se/manufacturer/semtech/ | SX1280IMLTRT | 75.44 | 75.44 | In stock | RF Transceiver Long range 2.4 GHz Wireless Transceiver
SKY66122-11 | 1 | https://www.mouser.se/ProductDetail/Skyworks-Solutions-Inc/SKY66122-11?qs=stqOd1AaK7%2F9zH4JdBCX2A%3D%3D | 873-SKY66122-11 | https://www.mouser.se/manufacturer/skyworks-solutions/ | SKY66122-11 | 40.48 | 40.48 | In stock | RF Front End OFDM, 863 to 928 MHz, Wi-SUN, FEM
B-G431B-ESC1 | 5 | https://www.mouser.se/ProductDetail/511-B-G431B-ESC1 | 511-B-G431B-ESC1 | https://www.mouser.se/manufacturer/stmicroelectronics/ | B-G431B-ESC1 | 208.96 | 1044.8 | In stock | Datasheet
VS-5EWH06FN-M3 | 4 | https://www.mouser.se/ProductDetail/Vishay-Semiconductors/VS-5EWH06FN-M3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 | 78-VS-5EWH06FN-M3 | https://www.mouser.se/manufacturer/vishaysemiconductors/ | VS-5EWH06FN-M3 | 10 | 48 | In stock | Kicker circuit
SMAJ20A | 3 | https://www.mouser.se/ProductDetail/Littelfuse/SMAJ20A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 | 576-SMAJ20A | https://www.mouser.se/manufacturer/littelfuse/ | SMAJ20A | 4 | 28 | In stock | Kicker circuit
TLP3910(C20-TP | 3 | https://www.mouser.se/ProductDetail/Toshiba/TLP3910C20-TPE?qs=TuK3vfAjtkUvVtweYOqjVw== | 757-TLP3910C20-TPE | https://www.mouser.se/manufacturer/toshiba-semiconductors/ | TLP3910(C20-TP | 36 | 46 | In stock | Kicker circuit
ECW-FD2J823KQ | 3 | https://www.mouser.se/ProductDetail/Panasonic/ECW-FD2J823KQ?qs=7EBvPakHacV3NgMNuq1u4w== | 667-ECW-FD2J823KQ | https://www.mouser.se/manufacturer/panasonicec/ | ECW-FD2J823KQ | 6 | 64 | In stock | Kicker circuit
CKG57NX7R2J474M500JH | 3 | https://www.mouser.se/ProductDetail/TDK/CKG57NX7R2J474M500JH?qs=NRhsANhppD%2BAmXDR5rVERg== | 810-CKG57NX7R2J474M | https://www.mouser.se/manufacturer/tdk/ | CKG57NX7R2J474M500JH | 46 | 58 | In stock | Kicker circuit
US1M | 3 | https://www.mouser.se/ProductDetail/Taiwan-Semiconductor/US1M?qs=tHU/lV7kTyQtvhnvJdnZJw== | 821-US1M | https://www.mouser.se/manufacturer/taiwan-semiconductor/ | US1M | 3 | 11 | In stock | Kicker circuit
FQB4N80TM | 3 | https://www.mouser.se/ProductDetail/onsemi-Fairchild/FQB4N80TM?qs=FOlmdCx%2BAA3dgdfgWff8ng== | 512-FQB4N80TM | https://www.mouser.se/manufacturer/fairchild-semiconductor/ | FQB4N80TM | 25 | 7 | In stock | Kicker circuit
IKB40N65ES5ATMA1 | 2 | https://www.mouser.se/ProductDetail/Infineon-Technologies/IKB40N65ES5ATMA1?qs=MLItCLRbWsxz7jtfFbVz2w%3D%3D | 726-IKB40N65ES5ATMA1 |  | IKB40N65ES5ATMA1 | 43.93 | 87.86 |  | Kicker Circuit
195207-231 | 1 | https://www.mouser.se/ProductDetail/Ledex/195207-231?qs=byeeYqUIh0N3hSxJ8HFfVg== | 906-195207-231 | https://www.mouser.se/manufacturer/ledex/ | 195207-231 | 426 | 19 | In stock | Kicker circuit
Wheel hub 4mm | 4 | https://www.electrokit.com/axelnav-med-klamfaste-4mm | 41020172 | https://www.gobilda.com/ | 1309-0016-0004 | 139 | 556 | in stock | Kicker circuit
Raspberry Pi 4 Model B/8GB | 1 | https://www.electrokit.com/raspberry-pi-4-model-b/8gb | 41017664 - Raspberry Pi | https://www.raspberrypi.com/ |  | 979 | 979 | In stock | Can be substituted with Raspberry Pi 4 Model B/4GB
Raspberry Pi Kameramodul 3 | 1 | https://www.electrokit.com/raspberry-pi-kameramodul-3-12mp-75 | 41020240 - Raspberry Pi | https://www.raspberrypi.com/ |  | 369 | 369 | In stock | Needs to be ordered with Raspberry Pi 4 Model B/8GB or Raspberry Pi 4 Model B/4GB
Bearings 5mm | 6 | https://www.electrokit.com/kullager-5mm | 41019266 |  |  | 15 | 90 | In stock | for dribbler assembly.
M3 threaded inserts 3mm, 50 pack | 1 | https://www.electrokit.com/ganginsats-m3-x-3mm-50-pack | 41018554 |  |  | 95 | 95 | In stock
APDS-9960 | 1 |  | 41013512 – Sparkfun | https://www.sparkfun.com/ | APDS-9960 | 199 | 199 | In stock | Chosen by UdeA, RGB sensor
TOF400C-VL53L1 | 1 | https://www.amazon.com/Teyleten-Robot-TOF400C-VL53L1X-Distance/dp/B0CLDKMGZR |  | https://www.mouser.se/manufacturer/stmicroelectronics/ | VL53L1CBV0FY/1 | 176.32 | 176.32 | In stock | Chosen by UdeA, could not find from another seller
VL6180 TOF | 1 | https://www.tinytronics.nl/en/sensors/distance/vl6180-time-of-flight-tof-distance-sensor |  | https://www.st.com/en/imaging-and-photonics-solutions/vl6180.html | VL6180 | 33 | 33 | In stock | Chosen by UdeA, could not find from another seller
XT60PW-M | 1 | https://www.tme.eu/se/details/xt60pw-m/dc-kontaktdon/amass/ | XT60PW-M | https://www.tme.eu/se/katalog/p,amass_1260/ | XT60PW-M | 11.21 | 11.21 | In stock | XT60 PCB connector
2-post pillow block, 32mm bore | 4 | https://eu.robotshop.com/products/servocity-1-side-2-post-pillow-block-32mm-bore | RP-Sct-2151 | https://www.servocity.com/ | 1602-0032 | 172.29 | 689.16 | On demand, 1 month delivery time | For extra support for the wheels, compatible with chosen hub.
B5P-VH | 10 | https://se.farnell.com/jst-japan-solderless-terminals/b5p-vh-lf-sn/connector-header-5pos-3-96mm-1row/dp/2399164 | JST (JAPAN SOLDERLESS TERMINALS) B5P-VH(LF)(SN) | https://se.farnell.com/b/jst-japan-solderless-terminals | B5P-VH(LF)(SN) | 5.21 | 52.1 | In stock | Motor connectors
OFFERT finns för nedanstående, se bifogad fil
OFFERT – BROADCOM AEDB-9140-A13 | 8 | https://uk.farnell.com/broadcom-limited/aedb-9140-a13/encoder-3channel-500cpr-8mm/dp/1161087 | BROADCOM AEDB-9140-A13 | https://uk.farnell.com/b/broadcom | AEDB-9140-A13 | 309 | 2472 | In stock | Offert från farnell med studentrabatt
 |  |  |  |  |  |  | 12904.47

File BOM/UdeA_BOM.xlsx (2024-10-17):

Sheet: Sheet1
Item |  | Description | Cantidad | Valor USD | Total USD | Factor | Total COP | Enlace | DOLAR | 4100
1 | insumo | Tarjeta sensor de ángulo de rotación | 52 | 2.4 | 126.8 | 1.8 | $936000.00 | https://didacticaselectronicas.com/index.php/view/productdetails/virtuemart_product_id/11439/virtuemart_category_id/109 | ROBOTS | 13
2 | insumo | SunnySky XS High Power X4110S Brushless Motors KV=340 | 52 | 47.0 | 2444.0 | 1.8 | $18036720.00 | https://sunnyskyusa.com/products/sunnysky-x4110s-motors
3 | insumo | Hobbywing Skywalker 60A V2 Brushless ESC BEC Speed Controller | 57 | 13.0 | 741.0 | 1.8 | $5468580.00 | https://www.aliexpress.us/item/4000092615779.html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
4 | insumo | BNO055 Accelerometer, Gyroscope, Magnetometer Sensor | 6 | 22.5 | 135.0 | 1.8 | $996300.00 | https://www.amazon.com/-/es/GY-BNO055-9-ejes-BNO055-ruptura-giroscopio/dp/B0CLJFYRX6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
5 | insumo | TransducerM AHRS 9-Axis IMU for Robotics & Autonomous Vehicles (TM151/TM171) | 6 | 45.0 | 270.0 | 1.8 | $1992600.00 | https://www.robotshop.com/products/transducerm-ahrs-9-axis-imu-for-robotics-autonomous-vehicles-tm151-tm171
6 | insumo | Sensor de distancia láser ToF. VL53L1 | 26 | 6.0 | 155.0 | 1.8 | $1144000.00 | https://www.didacticaselectronicas.com.co/shop/tof400c-vl53l1-sensor-de-distancia-laser-tof-vl53l1-21008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
7 | insumo | Sensor de distancia láser ToF. VL6180 | 13 | 3.1 | 40.2 | 1.8 | $296405.20 | https://www.didacticaselectronicas.com.co/shop/tof050c-vl6180x-sensor-de-distancia-laser-tof-vl6180-21009
8 | insumo | Kit 4 ESP32-S3-DevKitC-1-N16R8 | 4 | 27.0 | 108.0 | 1.8 | $797040.00 | https://www.amazon.com/dp/B0D3C378SJ?ref=ppx_yo2ov_dt_b_fed_asin_title
9 | insumo | Camaras sistema de vision | 4 | 80.0 | 320.0 | 1.8 | $2361600.00 | https://www.amazon.com/-/es/obturador-angular-velocidad-computadora-Tablero/dp/B0D41BSBTS
10 | equipo | SBC VIM4 8GB-RAM con NPU y kit activo de refrigeracion | 5 | 209.0 | 1045.0 | 1.8 | $7712100.00 | https://www.khadas.com/product-page/vim4
11 | insumo | Adaptador VIM4 | 5 | 30.0 | 150.0 | 1.8 | $1107000.00 | https://www.khadas.com/product-page/30w-usb-c-adapter
12 | insumo | Cable USB-C Adaptador VIM4 | 5 | 2.5 | 12.5 | 1.8 | $92250.00 | https://www.khadas.com/product-page/usb-c-cable-male-to-male
13 | insumo | New M2X Extension VIM4 | 5 | 8.0 | 40.0 | 1.8 | $295200.00 | https://www.khadas.com/product-page/new-m2x-extension
14 | insumo | SSD para VIM4 | 5 | 70.0 | 350.0 | 1.8 | $2583000.00 | https://www.amazon.com/-/es/velocidades-almacenamiento-actualizado-computadora-MZ-V9E1T0B/dp/B0CRCC9863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
15 | insumo | Tripodes para camaras | 4 | 29.0 | 116.0 | 1.8 | $856080.00 | https://www.amazon.com/-/es/Tr%C3%ADpodes-grabaci%C3%B3n-resistente-profesionales-compatibles/dp/B0B1HJ2YSH
16 | insumo | Turnigy nano-tech 1550mah 6S 65~130C Lipo Pack | 12 | 20.0 | 240.0 | 1.8 | $1771200.00 | https://hobbyking.com/en_us/turnigy-nano-tech-1550mah-6s-65-130c-lipo-pack-450l-heli.html
17 | insumo | Cable siliconado 18 AWG negro 5 metros | 12 | 2.4 | 28.9 | 1.8 | $213429.60 | https://es.aliexpress.com/item/1005001454777401.html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
18 | insumo | Cable siliconado 18 AWG rojo 5 metros | 12 | 2.4 | 28.9 | 1.8 | $213429.60 | https://es.aliexpress.com/item/1005001454777401.html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
19 | insumo | Cable siliconado 14 AWG negro 5 metros | 6 | 5.1 | 30.6 | 1.8 | $225828.00 | https://es.aliexpress.com/item/1005001454777401.html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
20 | insumo | Cable siliconado 14 AWG rojo 5 metros | 6 | 5.1 | 30.6 | 1.8 | $225828.00 | https://es.aliexpress.com/item/1005001454777401.html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
21 | insumo | Cable siliconado 10 AWG negro 5 metros | 2 | 15.5 | 31.0 | 1.8 | $228780.00 | https://es.aliexpress.com/item/1005001454777401.html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
22 | insumo | Cable siliconado 10 AWG rojo 5 metros | 2 | 15.5 | 31.0 | 1.8 | $228780.00 | https://es.aliexpress.com/item/1005001454777401.html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
23 | insumo | Tornillos Phillips de cabeza redonda roscada métricos, tuercas y arandelas (W SET) | 5 | 31.58 | 157.9 | 1.8 | $1165302.00 | https://es.aliexpress.com/item/1005006809717413.html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
24 | insumo | Filamento tipo ASA 1.75mm negro Kg | 6 | 30 | 180.0 | 1.8 | $1328400.00 | https://www.amazon.com/Polymaker-Filament-Resistant-Weather-Cardboard/dp/B09DKPYYBP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
25 | insumo | Filamento tioo PA6-CF 1.75mm negro 500g | 4 | 40 | 160.0 | 1.8 | $1180800.00 | https://www.amazon.com/Polymaker-Fiberon-PA6-CF-Filamento-filamento/dp/B0D4QDTHPQ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
26 | insumo | Filamento Polymaker TPU95-HF negro 1 Kg | 3 | 50 | 150.0 | 1.8 | $1107000.00 | https://www.amazon.com/Polymaker-Filamento-filamento-poliuretano-termopl%C3%A1stico/dp/B09KLGL459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
27 | insumo | ANYCUBIC ABS-Like Resin Pro 2 Gris x 4Kg | 2 | 67 | 134.0 | 1.8 | $988920.00 | https://www.amazon.com/impresora-resistencia-precisi%C3%B3n-compatibilidad-impresoras/dp/B0CPV7DB1M
28 | insumo | ANYCUBIC ABS-Like Resin Pro 2 Negra x 2kg | 2 | 40 | 80.0 | 1.8 | $590400.00 | https://www.amazon.com/impresora-resistencia-precisi%C3%B3n-compatibilidad-impresoras/dp/B0CPV7DB1M
29 | insumo | ANYCUBIC ABS-Like Resin Pro 2 Blanca x 2kg | 2 | 40 | 80.0 | 1.8 | $590400.00 | https://www.amazon.com/impresora-resistencia-precisi%C3%B3n-compatibilidad-impresoras/dp/B0CPV7DB1M
30 | otros | Grama sintetica 2x5mts | 8 | 54.2 | 433.6 | 1.8 | $3200000.00 | https://www.homecenter.com.co/homecenter-co/product/448419/pasto-grama-sintetica-2x5mt-espesor-10mm-verde/448419/
31 | insumo | 10m Termoencogible negro de 2mm | 2 | 1.9 | 3.7 | 1.8 | $27601.20 | https://es.aliexpress.com/item/1005007492115218.html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
32 | insumo | 10m Termoencogible rojo de 2mm | 2 | 1.9 | 3.8 | 1.8 | $27748.80 | https://es.aliexpress.com/item/1005007489518944.html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
33 | insumo | 10m Termoencogible negro de 4mm | 2 | 2.5 | 5.0 | 1.8 | $36900.00 | https://es.aliexpress.com/item/1005007492115218.html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
34 | insumo | 10m Termoencogible rojo de 4mm | 2 | 2.5 | 5.1 | 1.8 | $37342.80 | https://es.aliexpress.com/item/1005007489518944.html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
35 | insumo | Conversor DC-DC salida @5V 1.6A | 26 | 0.7 | 18.3 | 1.8 | $135200.00 | https://www.didacticaselectronicas.com/~didactic/index.php/view/productdetails/virtuemart_product_id/12027/virtuemart_category_id/837
36 | insumo | Conversor DC-DC salida@ 9V 1.1A | 26 | 0.7 | 18.3 | 1.8 | $135200.00 | https://www.didacticaselectronicas.com/~didactic/index.php/view/productdetails/virtuemart_product_id/12028/virtuemart_category_id/839
37 | insumo | Conversor DC-DC salida @ 12V 0.8A | 26 | 0.7 | 18.3 | 1.8 | $135200.00 | https://www.didacticaselectronicas.com/~didactic/index.php/view/productdetails/virtuemart_product_id/12029/virtuemart_category_id/840
38 | insumo | Conversor DC-DC salida @ 3.3V 1.8A | 26 | 0.7 | 18.3 | 1.8 | $135200.00 | https://www.didacticaselectronicas.com/~didactic/index.php/view/productdetails/virtuemart_product_id/12026/virtuemart_category_id/838
39 | insumo | 10 pairs (male-female) Bullet connectors 3.5mm | 30 | 1.1 | 33.0 | 1.8 | $243540.00 | https://es.aliexpress.com/item/1005006400659486.html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
40 | insumo | 10 pairs (male-female) Bullet connectors 4mm | 20 | 1.6 | 32.0 | 1.8 | $236160.00 | https://es.aliexpress.com/item/1005006400659486.html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
41 | insumo | 50 pairs (male-female) connector XT90 | 1 | 55.0 | 55.0 | 1.8 | $405900.00 | https://es.aliexpress.com/item/1005003614260098.html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
42 | insumo | 50 pairs (male-female) connector XT60 | 1 | 15.0 | 15.0 | 1.8 | $110700.00 | https://es.aliexpress.com/item/1005006860943414.html?scm_id=1007.40000.327270.0&scm-url=1007.40000.327270.0
43 | insumo | Extensión eléctrica10m | 5 | 4.1 | 20.3 | 1.8 | $150000.00 | https://www.didacticaselectronicas.com.co/shop/wj-c01-10m-extension-electrica-10m-3-tomas-naranja-2x14-19340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
44 | insumo | Multitoma 6 salidas 3m | 5 | 12.2 | 61.0 | 1.8 | $450000.00 | https://www.homecenter.com.co/homecenter-co/product/224676/multitoma-6-salidas-3m/224676/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
45 | insumo | Enrutador Wi-Fi 6 AX3000, Internet de doble banda | 1 | 120.0 | 120.0 | 1.8 | $885600.00 | https://www.amazon.com/TP-Link-WiFi-AX3000-Smart-Router/dp/B0BTD7V93F?adgrpid=81699018167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
46 | otros | Mesa plegable | 2 | 24.4 | 48.8 | 1.8 | $360000.00 | https://www.homecenter.com.co/homecenter-co/product/317175/mesa-plegable-metal-polietileno-blanco-180x75x74-cm/317175/
47 | otros | Silla Para Camping Plegable Sin Brazos color negro | 4 | 6.8 | 27.1 | 1.8 | $200000.00 | https://www.homecenter.com.co/homecenter-co/product/896589/silla-para-camping-plegable-sin-brazos-textil-multicolor/896589/
49 | insumo | Motor dribbling ChiHai Motor CHB-BLDC4260 DC24V 8000RPM 42mm Package A | 7 | 17.1 | 120.0 | 1.8 | $885969.00 | https://es.aliexpress.com/item/4000848454154.html?mp=1
50 | insumo | Placa High Speed Steel 4x20x200 mm | 14 | 6.0 | 84.0 | 1.8 | $619920.00 | https://es.aliexpress.com/item/1005002836006885.html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
51 | insumo | Placa de Alumino 6061 de 4x20x200mm | 14 | 1.0 | 14.0 | 1.8 | $103320.00 | https://es.aliexpress.com/item/1005006560298814.html?utparam-url=scene%3Asearch%7Cquery_from%3A
52 | insumo | Emtel 24 AWG - 1 lb (805 feet) 99.9% Pure Copper Wire, Enameled Magnetic Wire for Motor, Transformer, Magnetic Coil, & Electroculture Gardening, Winding Magnet Wire - 220°C (428°F) Thermal Class | 2 | 25.0 | 50.0 | 1.8 | $369000.00 | https://www.amazon.com/Emtel-24-AWG-transformador-electrocultural/dp/B08N6LY3JL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
53 | insumo | Resorte de tension 30mm largo y 6mm de diametro | 40 | 1.2 | 50.0 | 1.8 | $369000.00 | https://es.aliexpress.com/item/1005006529073133.html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
54 | insumo | Resorte de tension 40mm largo y 12mm de diametro | 40 | 1.6 | 62.0 | 1.8 | $457560.00 | https://es.aliexpress.com/item/1005006529073133.html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
55 | insumo | Resorte de tension 30mm largo y 4mm de diametro | 40 | 1.3 | 53.6 | 1.8 | $395568.00 | https://es.aliexpress.com/item/1005006529073133.html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
56 | insumo | 35KG 360 Degree Continuous Rotation Servo Digital Coreless 500μs-2500μs | 7 | 29.0 | 203.0 | 1.8 | $1498140.00 | https://www.amazon.com/Wishiot-TD-8135MG-Digital-Waterproof-500%CE%BCs-2500%CE%BCs/dp/B08JCVLSCK
57 | insumo | 1500μs/ 330hz 360 Continuous Rotation SPT5525LV-360 25KG Digital Servo | 14 | 6.0 | 84.0 | 1.8 | $619920.00 | https://www.amazon.com/Oumefar-Continuous-Rotation-SPT5525LV-360-Sensitivity/dp/B0BK9K425B
58 | insumo | Sensor de color RGB y de gestos, APDS9960 | 20 | 2.1 | 42.3 | 1.8 | $311994.20 | https://www.didacticaselectronicas.com.co/shop/gy-apds9960-sensor-de-color-rgb-y-de-gestos-apds9960-7021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
59 | otros | Organizador modular plástico 83x113x203mm | 64 | 2.2 | 140.3 | 1.8 | $1035776.00 | https://www.didacticaselectronicas.com.co/shop/om03caz-organizador-modular-plastico-83x113x203mm-21468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
60 | otros | Tela de Fieltro (Paño Lency) ancho 150 centimetros | 94 | 3.4 | 318.4 | 1.8 | $2350000.00 | https://casatextil.com.co/products/pano-lency-por-metros
61 | insumo | Molex 0530470310 | 180 | 0.163 | 29.4 | 1.8 | $216701.89 | https://www.digikey.com/en/products/detail/molex/0530470310/242854
62 | insumo | Molex 0510210300 | 180 | 0.118 | 21.2 | 1.8 | $156751.20 | https://www.digikey.com/en/products/detail/molex/0510210300/242843
63 | insumo | Molex 0530470410 | 55 | 0.275 | 15.1 | 1.8 | $111622.50 | https://www.digikey.com/en/products/detail/molex/0530470410/242855
64 | insumo | Molex 0510210400 | 55 | 0.198 | 10.9 | 1.8 | $80368.20 | https://www.digikey.com/en/products/detail/molex/0510210400/242844
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

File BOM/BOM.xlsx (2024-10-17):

Powertrain and Electronics
Ranking | Part name | Quantity | Distributor | Distributor Part Number | Manufacturer | Mfr Part number | Á price | Estimated cost | Lead time | Notes
Motor Wheel
1 | DF45L024048-A – Brushless DC motor | 4 | Nanotec (https://www.nanotec.com/eu/en/products/1786-df45l024048-a) | DF45L024048-A |  |  | 818.40 | 3273.60 | In stock | BLDC motors for the wheels, compact size, light weight, contains hall sensors for encoder feedback Sensored ESC is required if these are used
UdeA | MN5208 Navigator Type UAV Multi-Motor KV340 | 4 | T-motor (https://store.tmotor.com/product/mn5208-motor-navigator-type.html) | MN5208 |  |  | 1027.32 | 4109.28 | In stock | Motors similar to the one UdeA will use. Terrible torque at low speed, international shipping. Expensive compared to the DF45L024048-A
2 | Turnigy Multistar 4225-610Kv 16Pole Multi-Rotor Outrunner | 4 | HobbyKing (https://hobbyking.com/en_us/turnigy-multistar-4225-610kv-16pole-multi-rotor-outrunner.html) | 9392000008 |  |  | 297.00 | 1188.00 | In stock | Wheel BLDC Small form factor + low weight 86g Balanced RPM/V (610kV): Good tradeoff between speed and torque It provides good torque at low speeds which is needed for fast acceleration 16 poles, which gives pretty good control
3 | T-Motor MT2814 400 kv | 4 | RCflight (https://www.rcflight.se/visaprodukt.aspx?id=2951&p=t-motor-mt2814-400-kv) | MT2814-400KV | Tiger motors (https://uav-en.tmotor.com/) |  | 215.40 | 861.60 | In stock | Wheel BLDC, last batch
4 | Surpass Hobby Rocket 4114 400KV Quad Motor BL | 4 | elefun (https://www.elefun.se/p/prod.aspx?v=54896) | 54896 |  |  | 268.80 | 1075.20 | In stock | Wheel BLDC
Motor Dribbler
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

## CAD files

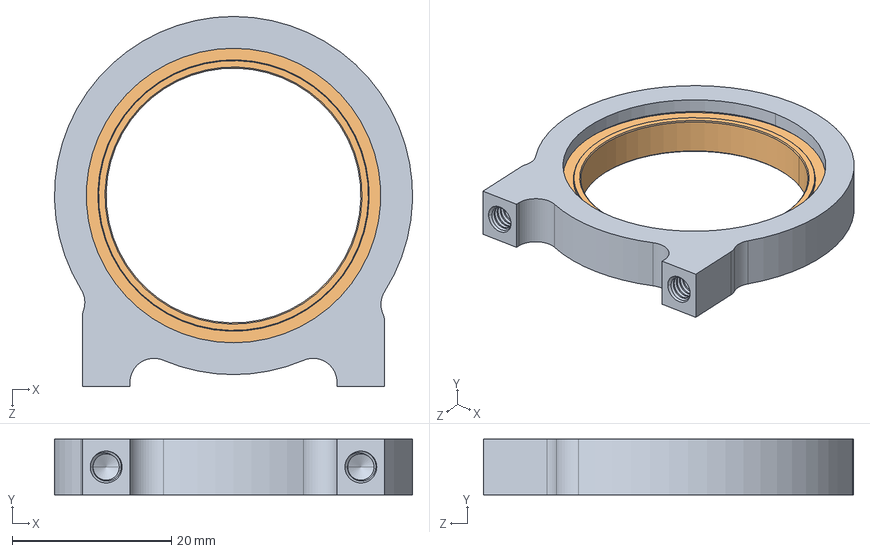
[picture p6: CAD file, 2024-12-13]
3D_Models/CAD_Files/Purchased_parts/1602-0032-0032 assembly.STEP
45.0 x 7.00 x 46.5 mm

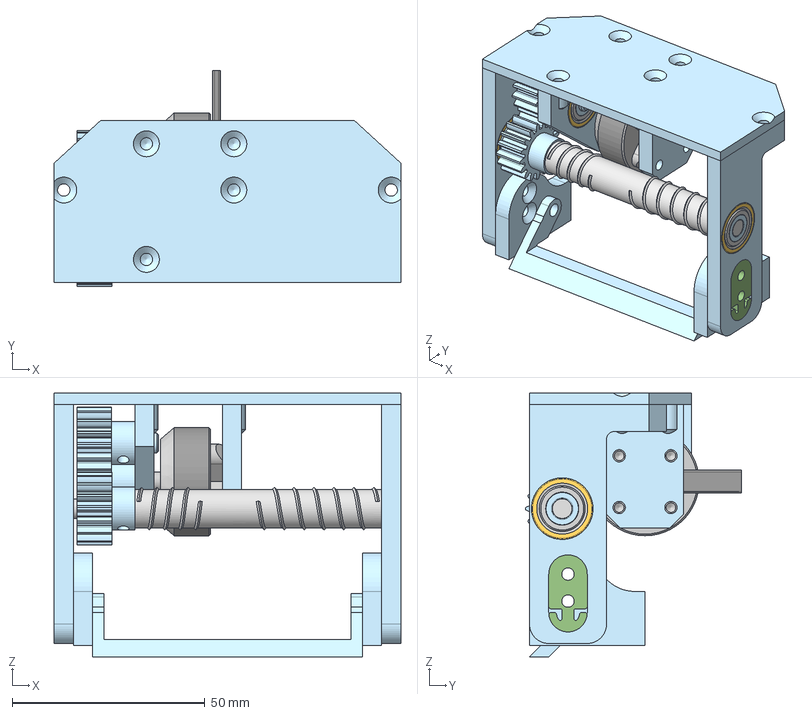
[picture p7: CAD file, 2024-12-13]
3D_Models/CAD_Files/step/Dribbler_Assembly.step
90.1 x 56.0 x 68.5 mm
Dribbler_mount x 2
Catch_bar _v3
dribbler_dampener x 2
Roller
Spur 1M 17T x 3
skf_bearing_625-z_2_1 x 16
pin_3dprint
Dribbler_bearing_holder
dribbler_motor

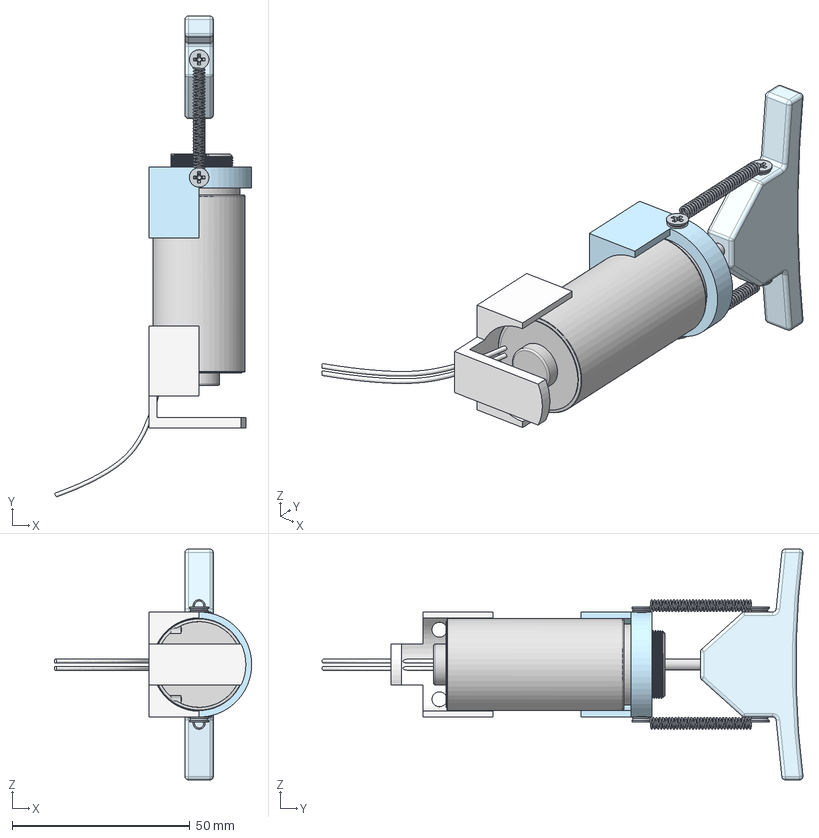
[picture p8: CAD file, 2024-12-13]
3D_Models/CAD_Files/step/Kicker_Assembly.step
55.6 x 135.4 x 65.0 mm
PH Countersunk flat head screw M3x0.5 x 6 x 6

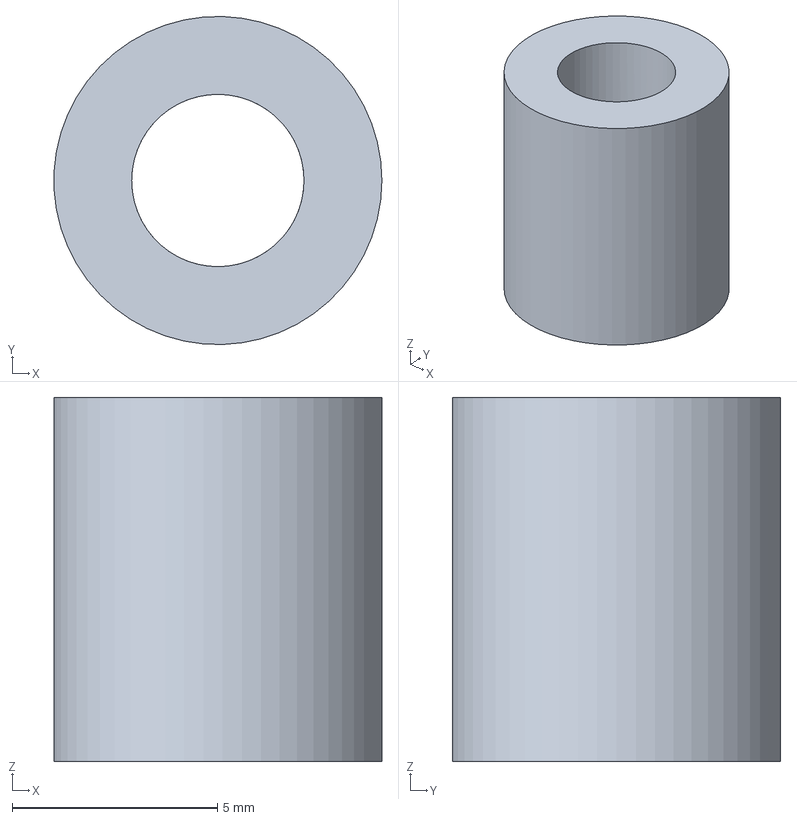
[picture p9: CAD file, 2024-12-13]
3D_Models/CAD_Files/step/offset_mainboard.step
7.99 x 8.00 x 8.88 mm

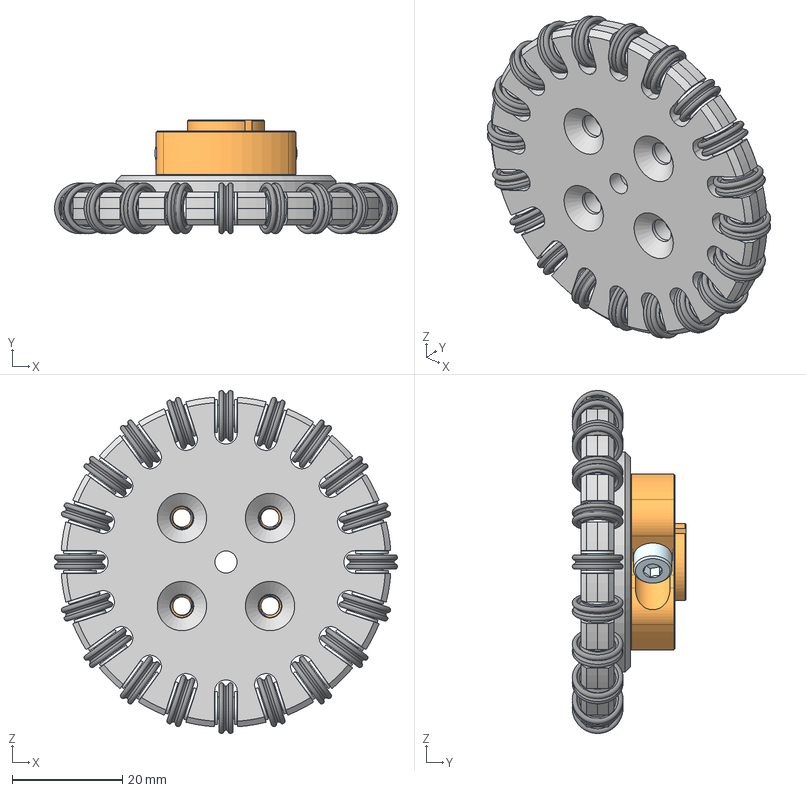
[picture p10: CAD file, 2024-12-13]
3D_Models/CAD_Files/step/Wheel_assembly.step
62.3 x 20.6 x 62.3 mm
Wheel x 2
x-ring x 20
TPE_bearing x 20
nylon_washer x 40
Parallel pin 2.5 x 8 x 20
Wheel_standoff
2800-0004-0014_90128A207 x 2

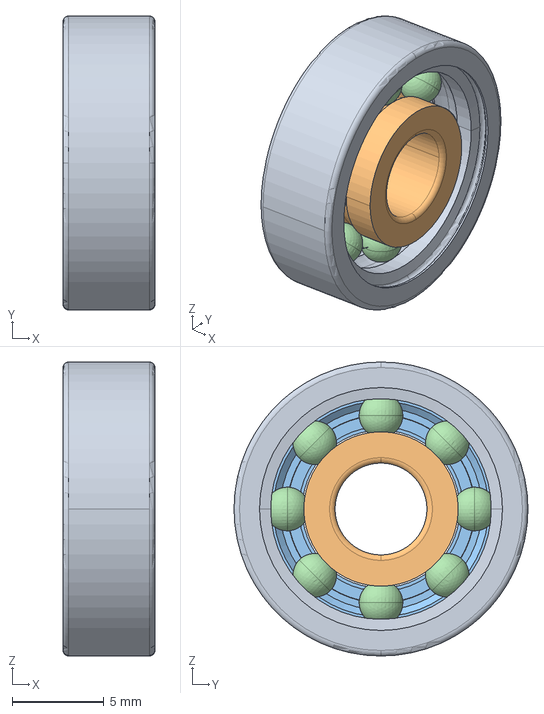
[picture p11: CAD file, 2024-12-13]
3D_Models/CAD_Files/Purchased_parts/skf_bearing_625-z_2.stp
5.00 x 16.0 x 16.0 mm

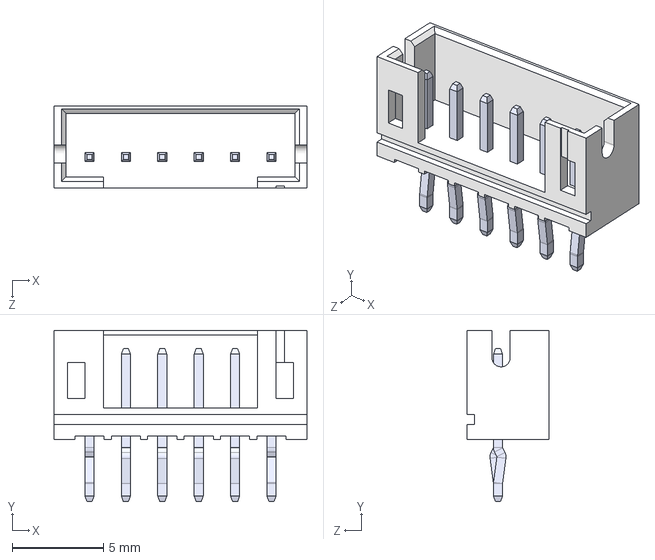
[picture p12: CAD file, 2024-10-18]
Circuits/Components/B6B-PH-K-S/B6B-PH-K-S--3DModel-STEP-56544.STEP
13.9 x 9.40 x 4.50 mm
pin x 6

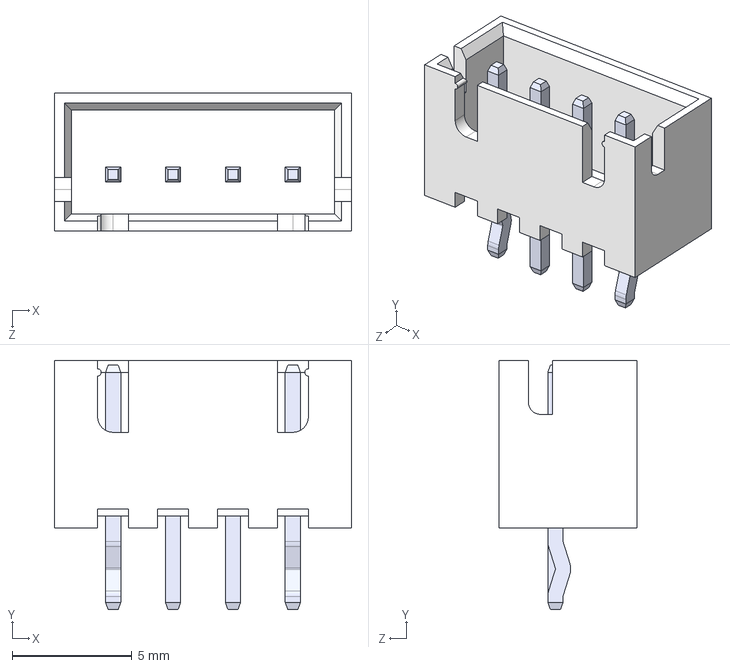
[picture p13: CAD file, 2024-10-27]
Circuits/Components/JST-XH 4A 2.54 mm pitch/B4B-XH-A--3DModel-STEP-56544.STEP
12.4 x 10.4 x 5.75 mm

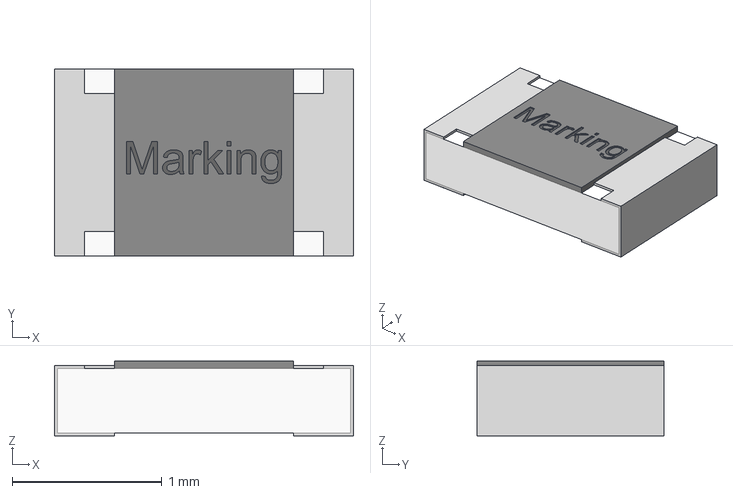
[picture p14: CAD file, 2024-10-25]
Circuits/Components/WE_560112120004_Libraries/IGS_WRIS-RSKS_0805 (rev1).igs
2.00 x 1.25 x 0.5 mm

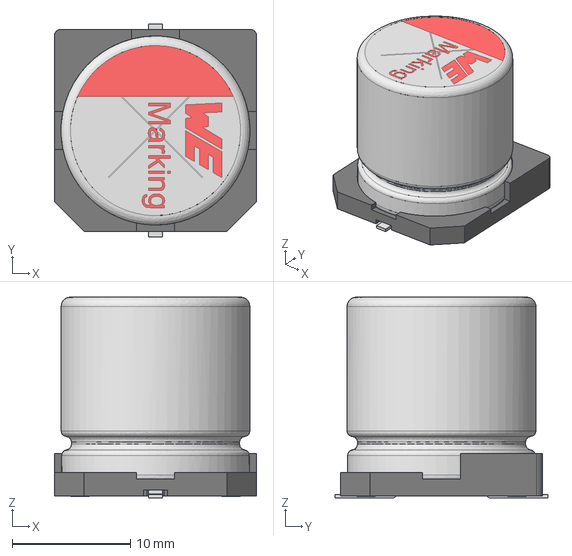
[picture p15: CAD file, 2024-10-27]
Circuits/Components/WE_865060663013_Libraries/IGS_WCAP-ASLL_16x17x6 (rev1).igs
17.1 x 18.0 x 17.0 mm

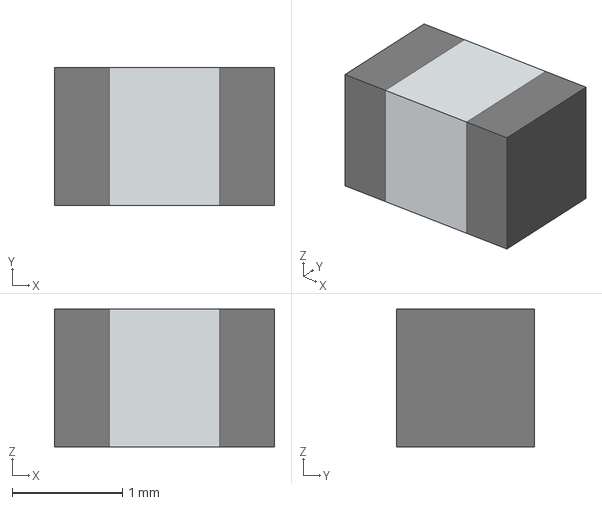
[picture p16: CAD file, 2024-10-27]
Circuits/Components/WE_885012107006_Libraries/IGS_MLCC_WACP-CSGP_0805 (rev1).igs
2.00 x 1.25 x 1.25 mm

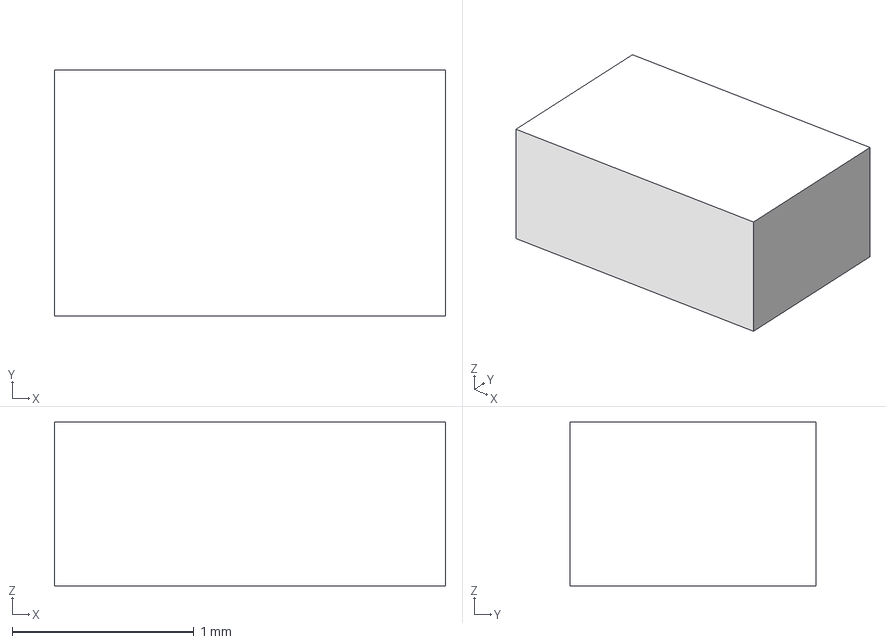
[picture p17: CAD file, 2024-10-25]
Circuits/Components/WE_885012207098_Libraries/IGS_WCAP-CSGP_0805_ 2.0x1.25x0.8x0 (rev1).igs
2.15 x 1.35 x 0.9 mm

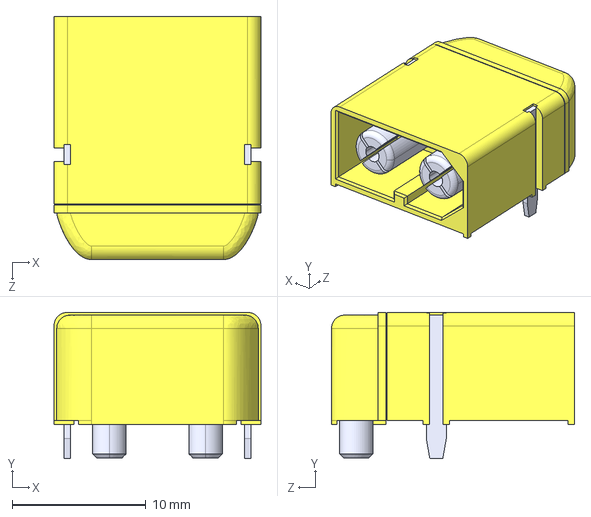
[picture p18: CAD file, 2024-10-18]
Circuits/Components/XT60PW-M/XT60PW-M--3DModel-STEP-269445.STEP
15.5 x 11.0 x 18.2 mm

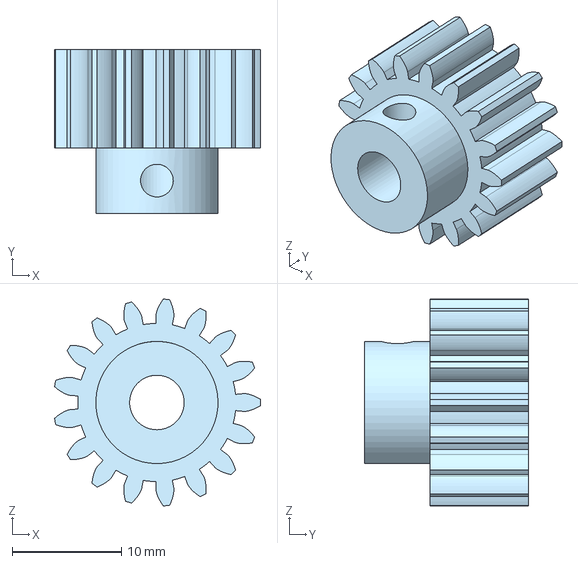
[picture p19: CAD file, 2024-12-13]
3D_Models/CAD_Files/Purchased_parts/traxxas_6490x_17t_m1_pinion.step
18.9 x 15.0 x 19.0 mm

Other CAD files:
Circuits/Mainboard/Mainboard/Unnamed-Mainboard.obj
Circuits/Mainboard/Mainboard/Mainboard.step
Circuits/Motor_Driver_carrier_board/Motor_Driver_carrier_board.step
3D_Models/CAD_Files/step/Encoder_disk.step
3D_Models/CAD_Files/Purchased_parts/195207-228.stp
3D_Models/CAD_Files/Purchased_parts/DF45L024048-A.stp
3D_Models/CAD_Files/step/Base_plate.step
3D_Models/CAD_Files/step/Battery.step
3D_Models/CAD_Files/step/Battery_mount_bottom.step
3D_Models/CAD_Files/step/Battery_mount_top.step
3D_Models/CAD_Files/step/Bearing-Oring.step
3D_Models/CAD_Files/step/Catch_bar.step
3D_Models/CAD_Files/step/Dribbler_bearing_holder.step
3D_Models/CAD_Files/step/Dribbler_dampener.step
3D_Models/CAD_Files/step/Dribbler_mount_left.step
3D_Models/CAD_Files/step/Dribbler_mount_right.step
3D_Models/CAD_Files/step/Encoder_backing.step
3D_Models/CAD_Files/step/Encoder_disk_mount.step
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

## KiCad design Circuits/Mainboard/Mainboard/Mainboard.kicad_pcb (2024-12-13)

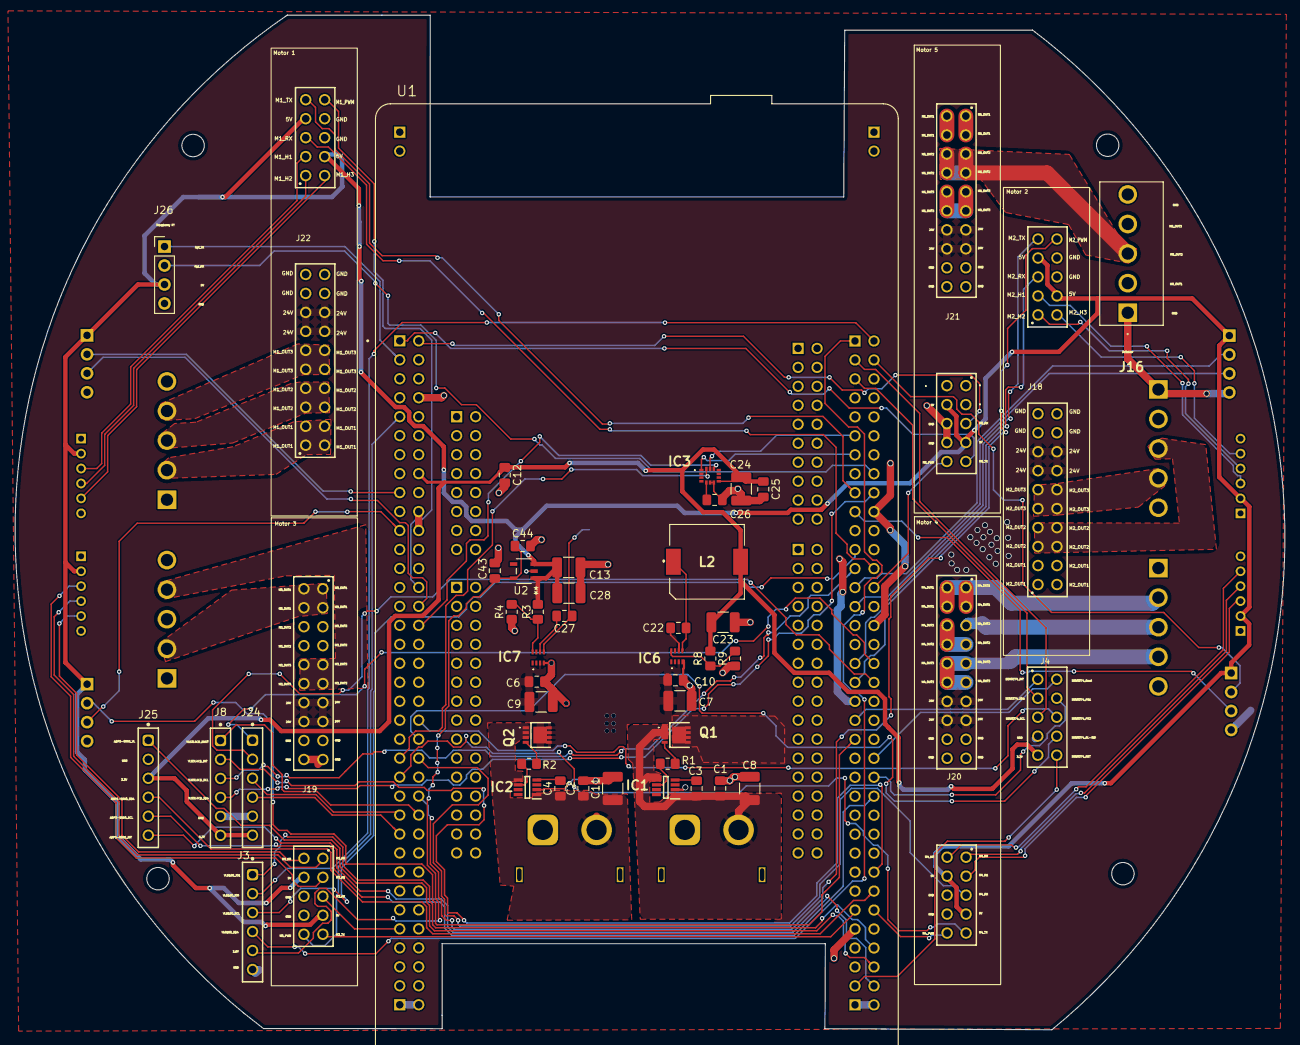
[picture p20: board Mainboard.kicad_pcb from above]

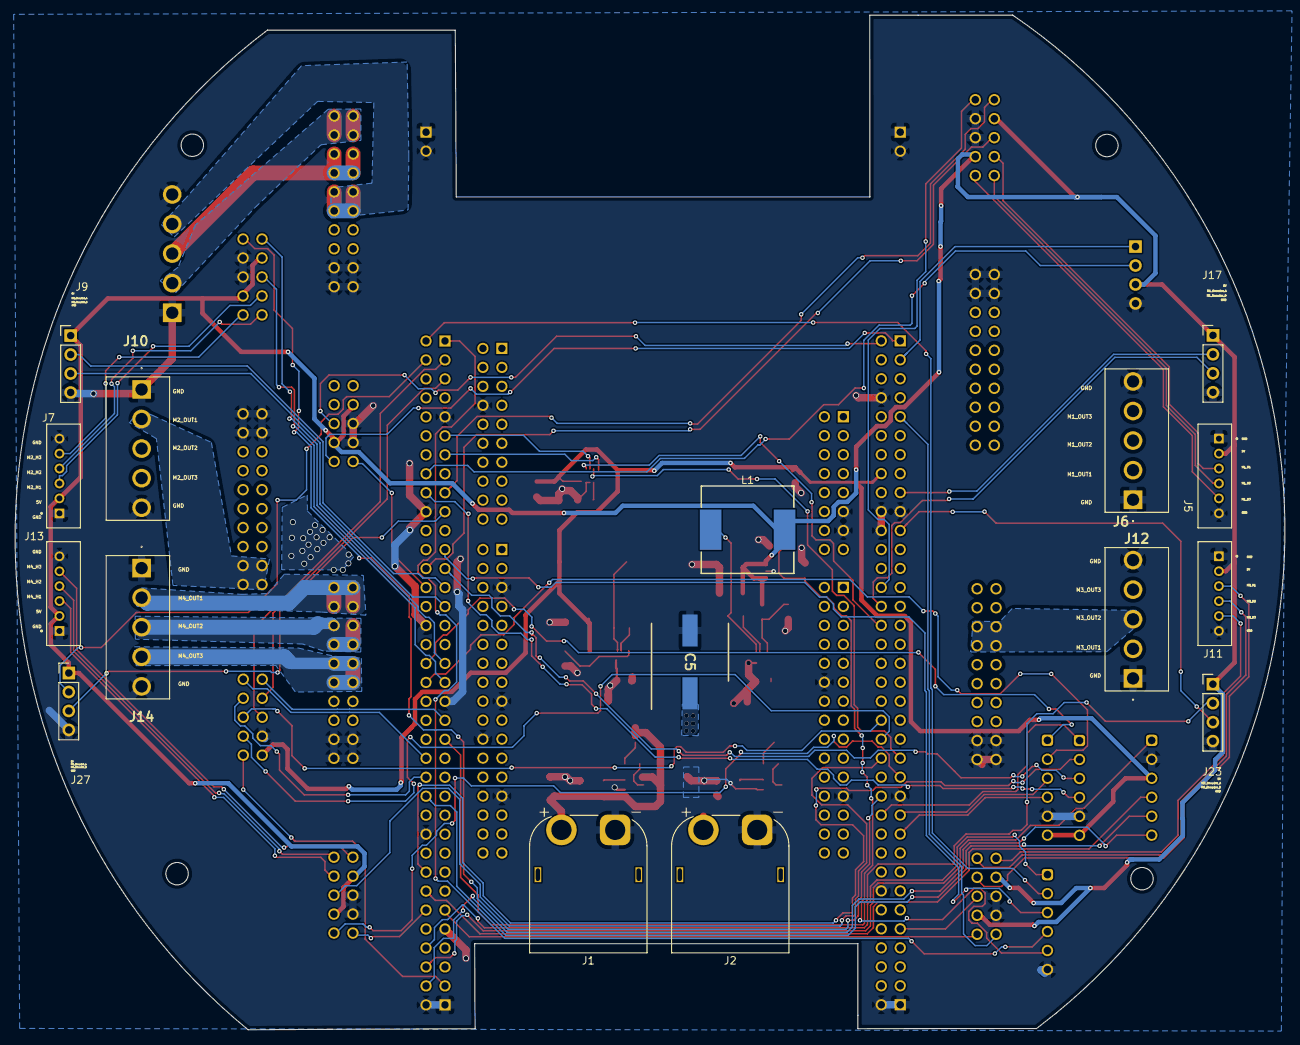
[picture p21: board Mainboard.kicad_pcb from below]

Board: 2 copper layers, 170.0 x 135.9 mm, 65 parts (16 on the bottom side), 100 nets.

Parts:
C1, C2, C3, C4, C6, C10, C12, C22, C25, C26, C27, C44: 0.1uF; C_0805_2012Metric_Pad1.18x1.45mm_HandSolder
C5: 220uF; CAPAE1030X1050N
C7, C8, C9, C11, C13, C24: 10uF; C_1210_3225Metric_Pad1.33x2.70mm_HandSolder
C23, C28: 47uF; C_1210_3225Metric_Pad1.33x2.70mm_HandSolder
C43: 4.7uF; C_0805_2012Metric_Pad1.18x1.45mm_HandSolder
IC1, IC2: LM74500QDDFRQ1; SOT65P280X110-8N
IC3: 2536030320001
IC6, IC7: TPS563300DRLR; TPS62932DRLR
J1, J2: XT60PW-M; AMASS_XT60PW-M_1x02_P7.20mm_Horizontal
J3, J8, J24, J25: Conn_01x06_Pin; 61300611821
J4: 61301021821
J5, J7, J11, J13: B6B-PH-K-S; JST_B6B-PH-K-S
J6, J10, J12, J14, J16: B5P-VH_LF__SN_
J9, J17, J23, J26, J27: Conn_01x04_Pin; PinHeader_1x04_P2.54mm_Vertical
J18, J19, J20, J21, J22: ESC_Adapter_socket
L1: 8.2uH; WE-HCC_1210
L2: 5.6uH; 7447714220
Q1, Q2: PSMN6R7-40MLDX; PSMN6R740MLDX
R1, R2: 10; R_0805_2012Metric_Pad1.20x1.40mm_HandSolder
R3: 52.3kOhm; R_0805_2012Metric_Pad1.20x1.40mm_HandSolder
R4, R9: 10kOhm; R_0805_2012Metric_Pad1.20x1.40mm_HandSolder
R8: 30.9kOhm; R_0805_2012Metric_Pad1.20x1.40mm_HandSolder
U1: NUCLEOH723ZG; MODULE_NUCLEOH723ZG
U2: ADP121-AUJZ28R7; UJ-5_ADI

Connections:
2.8V: C43.1, C44.1, J3.5, U2.5 (VOUT)
3.3V: C12.1, C23.2, C24.1, C25.1, IC3.8 (VDD), J4.9, J8.6, J24.6, J25.3, L2.2, R8.2, U1.CN11_16 (3V3)
5V: C13.1, C28.1, J5.2, J7.2, J9.1, J11.2, J13.2, J17.1, J18.24, J18.27, J19.24, J19.27, J20.24, J20.27, J21.24, J21.27, J22.24, J22.27, J23.1, J26.3, J27.1, L1.2, R3.2, U2.1 (VIN), U2.3 (EN)
24V: C5.1, C6.1, C7.1, C9.1, C10.1, IC6.3 (VIN), IC7.3 (VIN), J18.13, J18.14, J18.15, J18.16, J19.13, J19.14, J19.15, J19.16, J20.13, J20.14, J20.15, J20.16, J21.13, J21.14, J21.15, J21.16, J22.13, J22.14, J22.15, J22.16, Q1.5 (D_1), Q1.6 (D_2), Q1.7 (D_3), Q1.8 (D_4), Q1.9 (D_5), Q1.10 (D_6), Q1.11 (D_7), Q2.5 (D_1), Q2.6 (D_2), Q2.7 (D_3), Q2.8 (D_4), Q2.9 (D_5), Q2.10 (D_6), Q2.11 (D_7)
/24V_1: C1.1, C3.1, C8.1, IC1.1 (EN), IC1.5 (SOURCE), J1.2, Q1.1 (S_1), Q1.2 (S_2), Q1.3 (S_3)
/24V_2: C2.1, C4.1, C11.1, IC2.1 (EN), IC2.5 (SOURCE), J2.2, Q2.1 (S_1), Q2.2 (S_2), Q2.3 (S_3)
/ADPS-9960_INT: J25.6, U1.CN12_70 (PG6)
/ADPS-9960_SCL: J25.5, U1.CN12_50 (PF14)
/ADPS-9960_SDA: J25.4, U1.CN12_60 (PF15)
/ADPS-9960_VL: J25.1, U1.CN12_68 (PG5)
/M1_Encoder_A: J17.2, U1.CN11_17 (PA15)
/M1_Encoder_B: J17.3, U1.CN11_30 (PA1)
/M1_H1: J5.3, J22.23
/M1_H2: J5.4, J22.21
/M1_H3: J5.5, J22.22
/M1_OUT1: J6.2, J22.1, J22.2, J22.3, J22.4
/M1_OUT2: J6.3, J22.5, J22.6, J22.7, J22.8
/M1_OUT3: J6.4, J22.9, J22.10, J22.11, J22.12
/M1_PWM: J22.30, U1.CN11_28 (PA0)
/M1_RX: J22.25, U1.CN12_26 (PB15)
/M1_TX: J22.29, U1.CN12_17 (PB6)
/M2_Encoder_A: J9.2, U1.CN12_27 (PB4)
/M2_Encoder_B: J9.3, U1.CN12_29 (PB5)
/M2_H1: J7.3, J18.23
/M2_H2: J7.4, J18.21
/M2_H3: J7.5, J18.22
/M2_OUT1: J10.2, J18.1, J18.2, J18.3, J18.4
/M2_OUT2: J10.3, J18.5, J18.6, J18.7, J18.8
/M2_OUT3: J10.4, J18.9, J18.10, J18.11, J18.12
/M2_PWM: J18.30, U1.CN11_50 (PE5)
/M2_RX: J18.25, U1.CN12_37 (PA3)
/M2_TX: J18.29, U1.CN12_35 (PA2)
/M3_Encoder_A: J23.2, U1.CN12_43 (PD12)
/M3_Encoder_B: J23.3, U1.CN11_21 (PB7)
/M3_H1: J11.3, J19.23
/M3_H2: J11.4, J19.21
/M3_H3: J11.5, J19.22
/M3_OUT1: J12.2, J19.1, J19.2, J19.3, J19.4
/M3_OUT2: J12.3, J19.5, J19.6, J19.7, J19.8
/M3_OUT3: J12.4, J19.9, J19.10, J19.11, J19.12
/M3_PWM: J19.30, U1.CN11_9 (PF6)
/M3_RX: J19.25, U1.CN11_63 (PG9)
/M3_TX: J19.29, U1.CN12_61 (PG14)
/M4_Encoder_A: J27.2, U1.CN12_4 (PC6)
/M4_Encoder_B: J27.3, U1.CN12_19 (PC7)
/M4_H1: J13.3, J20.23
/M4_H2: J13.4, J20.21
/M4_H3: J13.5, J20.22
/M4_OUT1: J14.2, J20.1, J20.2, J20.3, J20.4
/M4_OUT2: J14.3, J20.5, J20.6, J20.7, J20.8
/M4_OUT3: J14.4, J20.9, J20.10, J20.11, J20.12
/M4_PWM: J20.30, U1.CN12_62 (PF11)
/M4_RX: J20.25, U1.CN11_46 (PE2)
/M4_TX: J20.29, U1.CN11_47 (PE3)
/M5_OUT1: J16.2, J21.1, J21.2, J21.3, J21.4
/M5_OUT2: J16.3, J21.5, J21.6, J21.7, J21.8
/M5_OUT3: J16.4, J21.9, J21.10, J21.11, J21.12
/M5_PWM: J21.30, U1.CN12_28 (PB14)
/M5_RX: J21.25, U1.CN11_2 (PC11)
/M5_TX: J21.29, U1.CN11_1 (PC10)
/Rpi_RX: J26.2, U1.CN12_16 (PB12)
/Rpi_TX: J26.1, U1.CN11_3 (PC12)
/SEN0374_BL-IND: J4.8, U1.CN11_44 (PG3)
/SEN0374_Boot: J4.2, U1.CN12_46 (PD14)
/SEN0374_INT: J4.1, U1.CN12_41 (PD13)
/SEN0374_PS1: J4.4, U1.CN12_48 (PD15)
/SEN0374_PS2: J4.6, U1.CN11_42 (PG2)
/SEN0374_RST: J4.10, U1.CN12_69 (PG4)
/SEN0374_SCL: J4.5, U1.CN12_3 (PB8)
/SEN0374_SDA: J4.3, U1.CN12_5 (PB9)
/VL53L4CD2_INT: J24.2, U1.CN12_38 (PF4)
/VL53L4CD2_SCL: J24.3, U1.CN11_51 (PF1)
/VL53L4CD2_SDA: J24.4, U1.CN11_53 (PF0)
/VL53L4CD2_SHUT: J24.1, U1.CN12_36 (PF5)
/VL53L4CD_INT: J8.2, U1.CN12_58 (PF3)
/VL53L4CD_SCL: J8.3, U1.CN12_25 (PB10)
/VL53L4CD_SDA: J8.4, U1.CN12_18 (PB11)
/VL53L4CD_SHUT: J8.1, U1.CN11_52 (PF2)
/VL6180_IO0: J3.2, U1.CN12_2 (PC8)
/VL6180_IO1: J3.1, U1.CN12_66 (PG8)
/VL6180_SCL: J3.3, U1.CN12_23 (PA8)
/VL6180_SDA: J3.4, U1.CN12_1 (PC9)
GND: C1.2, C2.2, C5.2, C6.2, C7.2, C8.2, C9.2, C10.2, C11.2, C12.2, C13.2, C23.1, C24.2, C25.2, C26.2, C28.2, C43.2, C44.2, IC1.2 (GND), IC2.2 (GND), IC3.6 (GND_1), IC3.7 (GND_2), IC6.4 (GND), IC7.4 (GND), J1.1, J2.1, J3.6, J4.7, J5.1, J5.6, J6.1, J6.5, J7.1, J7.6, J8.5, J9.4, J10.1, J10.5, J11.1, J11.6, J12.1, J12.5, J13.1, J13.6, J14.1, J14.5, J16.1, J16.5, J17.4, J18.17, J18.18, J18.19, J18.20, J18.26, J18.28, J19.17, J19.18, J19.19, J19.20, J19.26, J19.28, J20.17, J20.18, J20.19, J20.20, J20.26, J20.28, J21.17, J21.18, J21.19, J21.20, J21.26, J21.28, J22.17, J22.18, J22.19, J22.20, J22.26, J22.28, J23.4, J24.5, J25.2, J26.4, J27.4, R4.1, R9.1, U1.CN3_1 (GND_CN3), U1.CN3_2 (GND_CN3), U1.CN4_1 (GND_CN4), U1.CN4_2 (GND_CN4), U1.CN7_8 (GND_CN7), U1.CN8_11 (GND_CN8), U1.CN8_13 (GND_CN8), U1.CN9_12 (GND_CN9), U1.CN9_23 (GND_CN9), U1.CN10_5 (GND_CN10), U1.CN10_17 (GND_CN10), U1.CN10_22 (GND_CN10), U1.CN10_27 (GND_CN10), U1.CN11_8 (GND_CN11), U1.CN11_19 (GND_CN11), U1.CN11_20 (GND_CN11), U1.CN11_22 (GND_CN11), U1.CN11_49 (GND_CN11), U1.CN11_60 (GND_CN11), U1.CN12_9 (GND_CN12), U1.CN12_20 (GND_CN12), U1.CN12_32 (AGND_CN12), U1.CN12_39 (GND_CN12), U1.CN12_54 (GND_CN12), U1.CN12_63 (GND_CN12), U1.CN15_1 (GND_CN15), U1.CN15_2 (GND_CN15), U1.CN16_1 (GND_CN16), U1.CN16_2 (GND_CN16), U2.2 (GND)
unnamed: IC1.6 (GATE), R1.2
unnamed: C3.2, IC1.4 (VCAP)
unnamed: IC2.6 (GATE), R2.2
unnamed: C4.2, IC2.4 (VCAP)
unnamed: C22.2, IC6.6 (BST)
unnamed: IC6.8 (FB), R8.1, R9.2
unnamed: C22.1, IC6.5 (SW), L2.1
unnamed: C27.2, IC7.6 (BST)
unnamed: IC7.8 (FB), R3.1, R4.2
unnamed: C27.1, IC7.5 (SW), L1.1
unnamed: Q1.4 (G), R1.1
unnamed: Q2.4 (G), R2.1
VDD_IO: C26.1, IC3.5 (VDD_IO)
WSENS_CS: IC3.12 (CS), U1.CN11_32 (PA4)
WSENS_SAO: IC3.1 (SAO), U1.CN12_13 (PA6)
WSENS_SCL: IC3.13 (SCL), U1.CN12_11 (PA5)
WSENS_SDA: IC3.14 (SDA), U1.CN11_45 (PD7)

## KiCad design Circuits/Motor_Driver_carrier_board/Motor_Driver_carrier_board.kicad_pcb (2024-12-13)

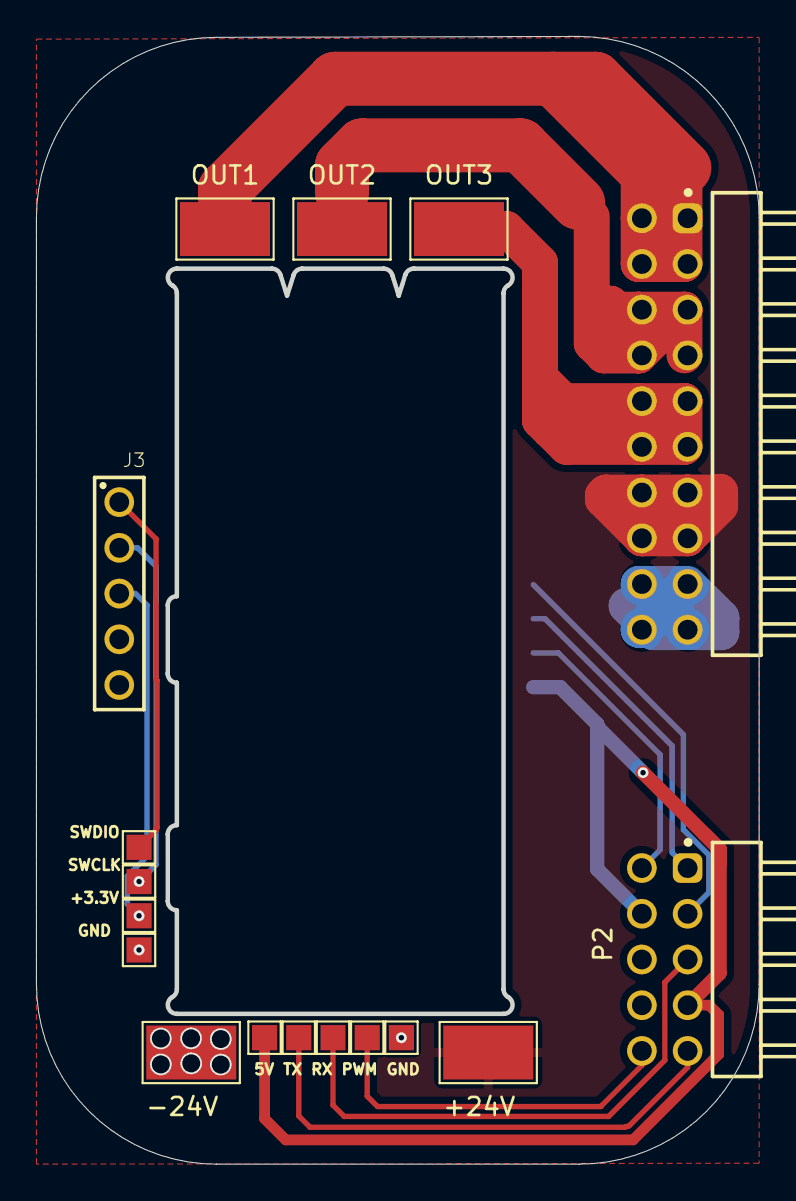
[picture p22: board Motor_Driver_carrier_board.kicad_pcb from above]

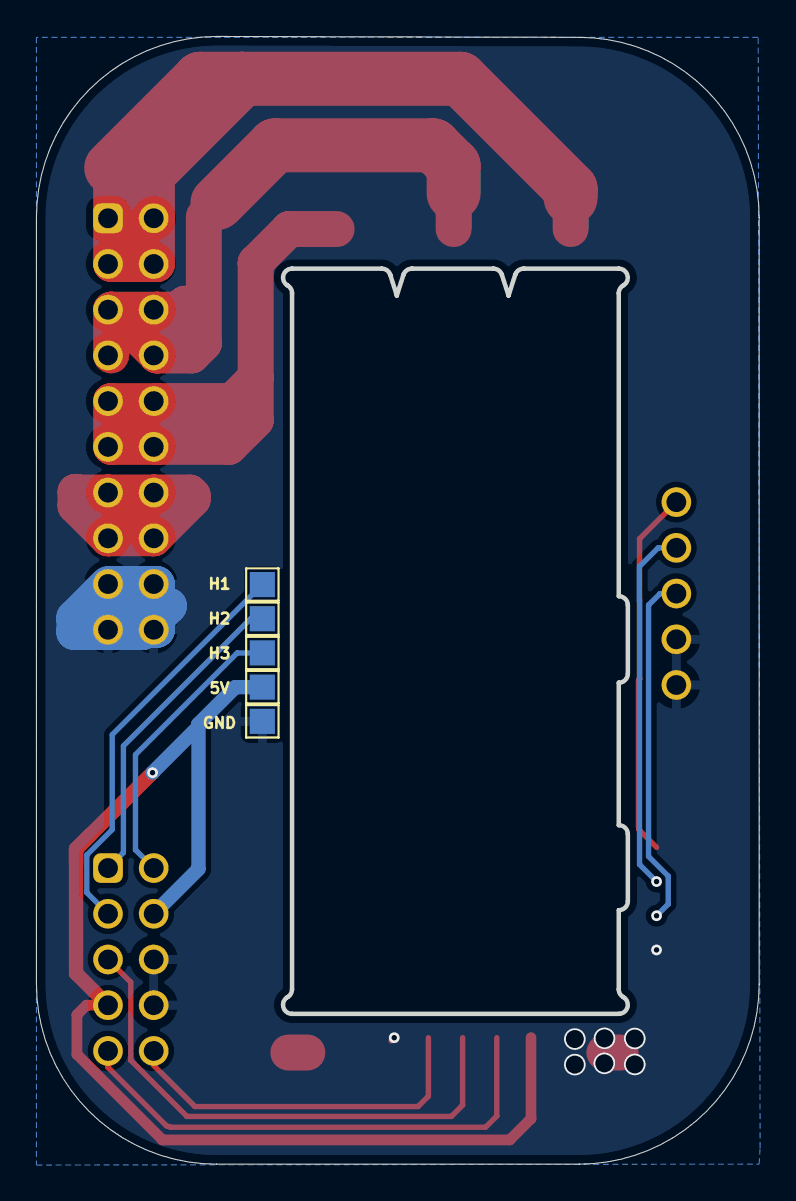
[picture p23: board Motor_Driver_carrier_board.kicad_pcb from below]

Board: 2 copper layers, 40.2 x 62.7 mm, 21 parts (5 on the bottom side), 15 nets.

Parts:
5V, 5V#2: TestPoint_Pad_1.4x1.4mm; TestPoint_Pad_1.0x1.0mm
+3.3V: TestPoint_Pad_1.4x1.4mm; TestPoint_Pad_1.0x1.0mm
+24V: OUT1; Solder_Pad_5.0x3.0mm
-24V: OUT1; Solder_Pad_5.0x3.0mm
GND: TestPoint_Pad_1.4x1.4mm; TestPoint_Pad_1.0x1.0mm
GND#2, GND#3: TestPoint_Pad_1.4x1.4mm; TestPoint_Pad_1.0x1.0mm
H1, H2, H3: TestPoint_Pad_1.4x1.4mm; TestPoint_Pad_1.0x1.0mm
J3: 61300511121
OUT1, OUT2, OUT3: OUT1; Solder_Pad_5.0x3.0mm
P2: ESC_Adapter_pins_right_angle
PWM: TestPoint_Pad_1.4x1.4mm; TestPoint_Pad_1.0x1.0mm
RX: TestPoint_Pad_1.4x1.4mm; TestPoint_Pad_1.0x1.0mm
SWCLK: TestPoint_Pad_1.4x1.4mm; TestPoint_Pad_1.0x1.0mm
SWDIO: TestPoint_Pad_1.4x1.4mm; TestPoint_Pad_1.0x1.0mm
TX: TestPoint_Pad_1.4x1.4mm; TestPoint_Pad_1.0x1.0mm

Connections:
3.3V: +3.3V.1, J3.3
5V: 5V.1, 5V#2.1, P2.24, P2.27
24V: +24V.1, P2.13, P2.14, P2.15, P2.16
GND: -24V.1, GND.1, GND#2.1, GND#3.1, J3.4, J3.5, P2.17, P2.18, P2.19, P2.20, P2.26, P2.28
H1: H1.1, P2.23
H2: H2.1, P2.21
H3: H3.1, P2.22
OUT1: OUT1.1, P2.1, P2.2, P2.3, P2.4
OUT2: OUT2.1, P2.5, P2.6, P2.7, P2.8
OUT3: OUT3.1, P2.9, P2.10, P2.11, P2.12
PWM: P2.30, PWM.1
RX: P2.25, RX.1
SWCLK: J3.2, SWCLK.1
SWDIO: J3.1, SWDIO.1
TX: P2.29, TX.1

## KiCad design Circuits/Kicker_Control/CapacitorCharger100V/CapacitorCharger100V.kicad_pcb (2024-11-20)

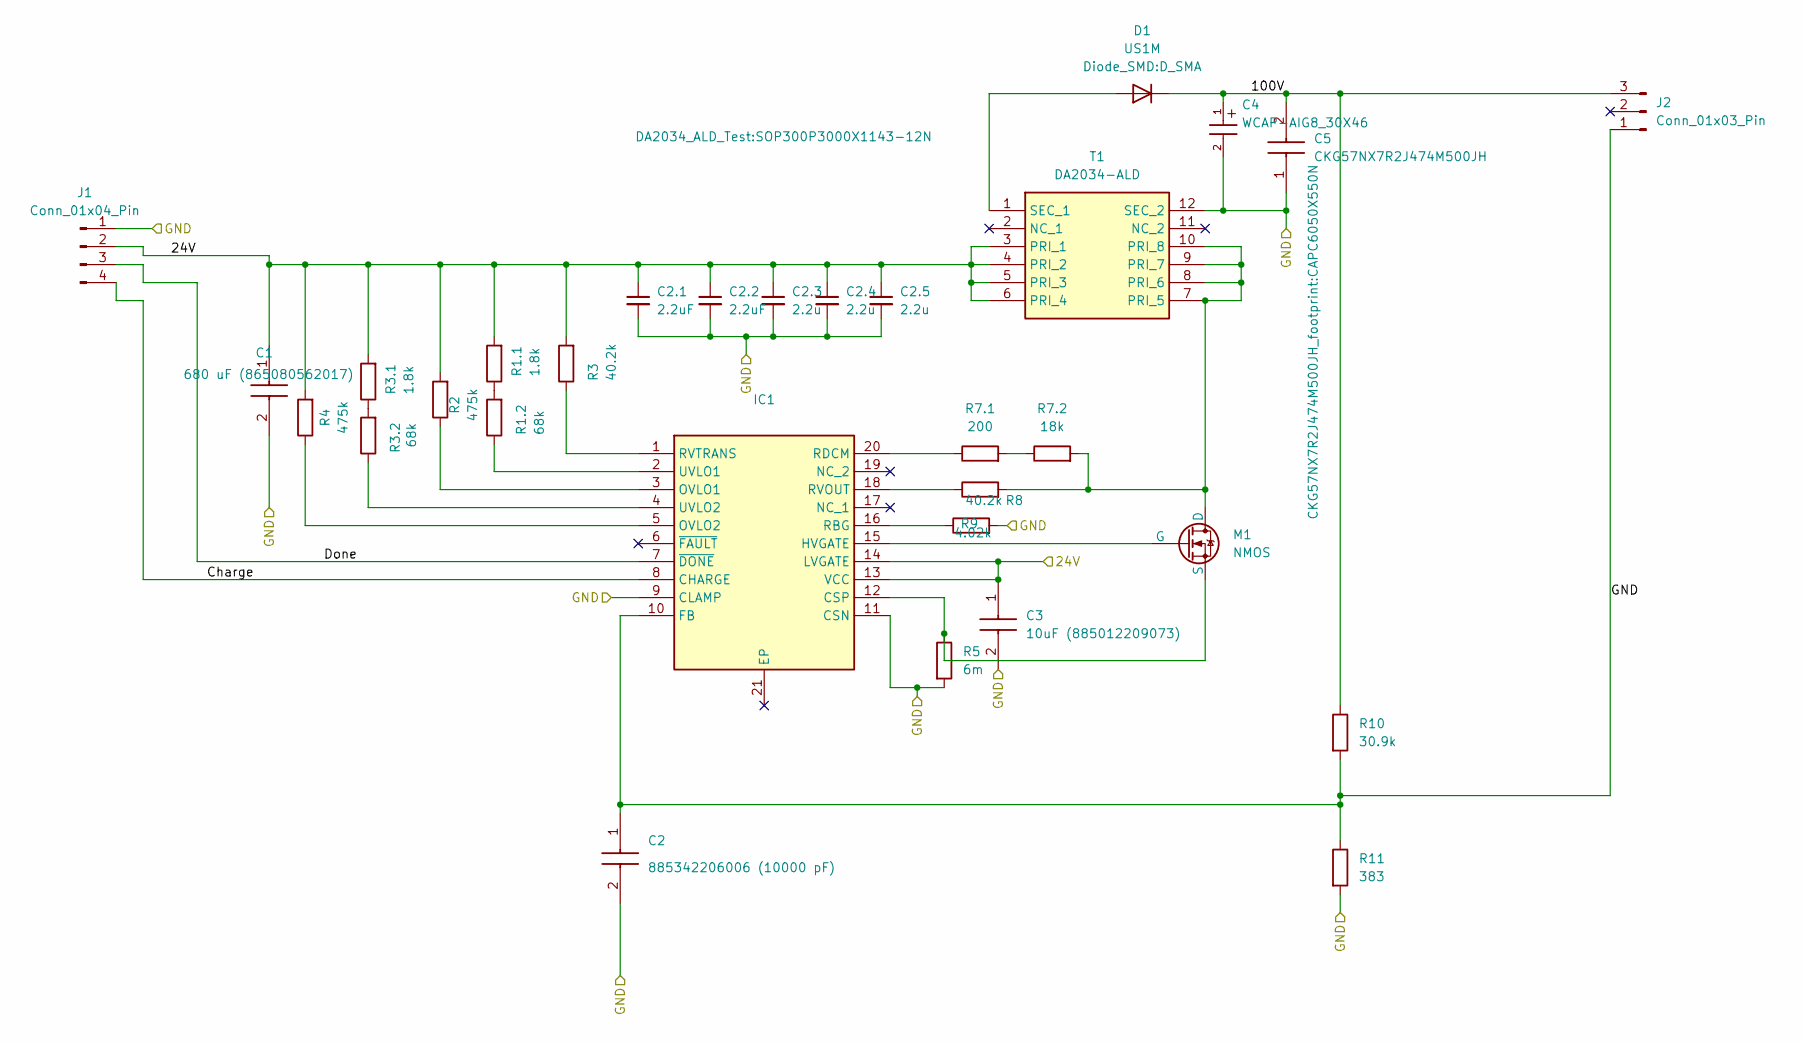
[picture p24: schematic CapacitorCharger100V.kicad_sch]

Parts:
C1: 680 uF (865080562017); CAPAE1350X1400N; Mouser Part Number 710-865080562017
C2: 885342206006 (10000 pF); CAPC1608X87N; Mouser Part Number 710-885342206006
C2.1, C2.2: 2.2uF; C_1210_3225Metric
C2.3, C2.4, C2.5: 2.2u; C_1210_3225Metric
C3: 10uF (885012209073); C_1210_3225Metric; Mouser Part Number 710-885012209073
C4: WCAP-AIG8_30X46; WCAP-AIG8_30X46_DXL_
C5: CKG57NX7R2J474M500JH; CAPC6050X550N; Manufacturer_Part_Number CKG57NX7R2J474M500JH
D1: US1M; D_SMA
IC1: LT3751IFE#PBF; SOP65P640X120-21N; Mouser Part Number 584-LT3751IFE#PBF
J1: Conn_01x04_Pin; PinHeader_1x04_P2.54mm_Vertical
J2: Conn_01x03_Pin; PinHeader_1x03_P2.54mm_Vertical
M1: NMOS; TO-263-3_TabPin2
R1.1, R3.1: 1.8k; R_0603_1608Metric
R1.2, R3.2: 68k; R_1206_3216Metric
R2, R4: 475k; R_0603_1608Metric
R3, R8: 40.2k; R_0603_1608Metric
R5: 6m; R_0805_2012Metric
R7.1: 200; R_0805_2012Metric
R7.2: 18k; R_0603_1608Metric
R9: 4.02k; R_0603_1608Metric
R10: 30.9k; R_1206_3216Metric
R11: 383; R_1206_3216Metric
T1: DA2034-ALD; SOP300P3000X1143-12N; Mouser Part Number 994-DA2034-ALD

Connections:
/24V: C1.1 (+), C2.1.1, C2.2.1, C2.3.1, C2.4.1, C2.5.1, C3.1, IC1.13 (VCC), IC1.14 (LVGATE), J1.2, R1.1.2, R2.2, R3.2, R3.1.2, R4.2, T1.3 (PRI_1), T1.4 (PRI_2), T1.5 (PRI_3), T1.6 (PRI_4)
/100V: C4.1, C5.2, D1.1 (K), J2.3, R10.1
/Charge: IC1.8 (CHARGE), J1.4
/Done: IC1.7 (~DONE), J1.3
/GND: C1.2 (-), C2.1, C2.2, C2.1.2, C2.2.2, C2.3.2, C2.4.2, C2.5.2, C3.2, C4.2, C5.1, IC1.9 (CLAMP), IC1.10 (FB), IC1.11 (CSN), J1.1, J2.1, R5.2, R9.2, R10.2, R11.1, R11.2, T1.12 (SEC_2)
unnamed: D1.2 (A), T1.1 (SEC_1)
unnamed: IC1.12 (CSP), M1.3 (S), R5.1
unnamed: IC1.15 (HVGATE), M1.2 (G)
unnamed: IC1.3 (OVLO1), R2.1
unnamed: IC1.5 (OVLO2), R4.1
unnamed: IC1.16 (RBG), R9.1
unnamed: IC1.20 (RDCM), R7.1.1
unnamed: IC1.18 (RVOUT), R8.1
unnamed: IC1.1 (RVTRANS), R3.1
unnamed: IC1.2 (UVLO1), R1.2.1
unnamed: IC1.4 (UVLO2), R3.2.1
unnamed: M1.1 (D), R7.2.2, R8.2, T1.7 (PRI_5), T1.8 (PRI_6), T1.9 (PRI_7), T1.10 (PRI_8)
unnamed: R1.1.1, R1.2.2
unnamed: R3.1.1, R3.2.2
unnamed: R7.1.2, R7.2.1

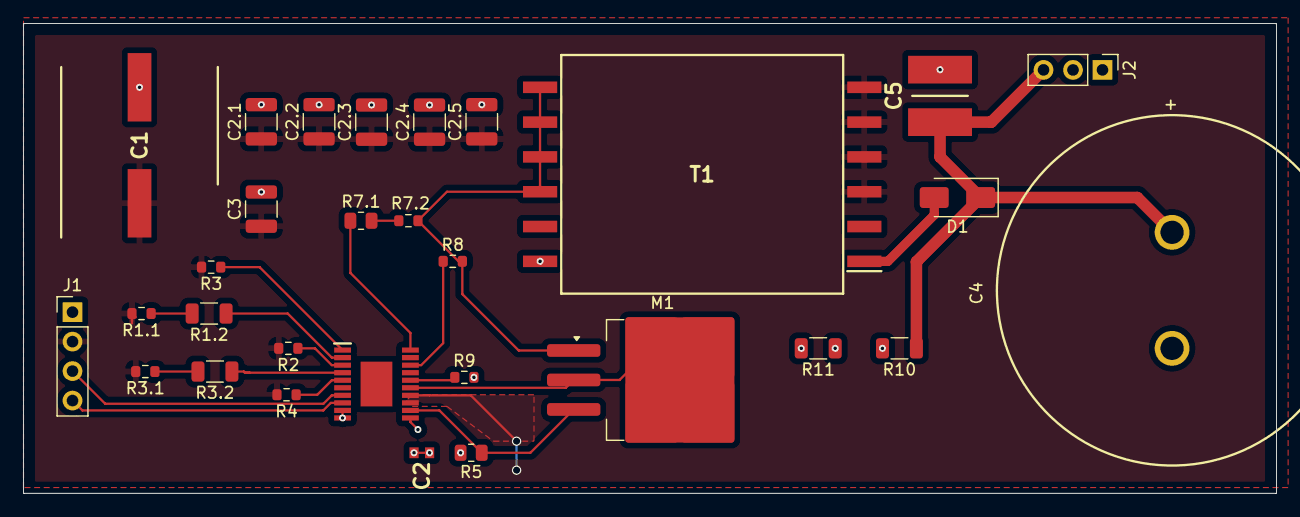
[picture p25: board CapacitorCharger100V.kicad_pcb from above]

Board: 2 copper layers, 108.0 x 40.5 mm, 30 parts (0 on the bottom side), 20 nets.

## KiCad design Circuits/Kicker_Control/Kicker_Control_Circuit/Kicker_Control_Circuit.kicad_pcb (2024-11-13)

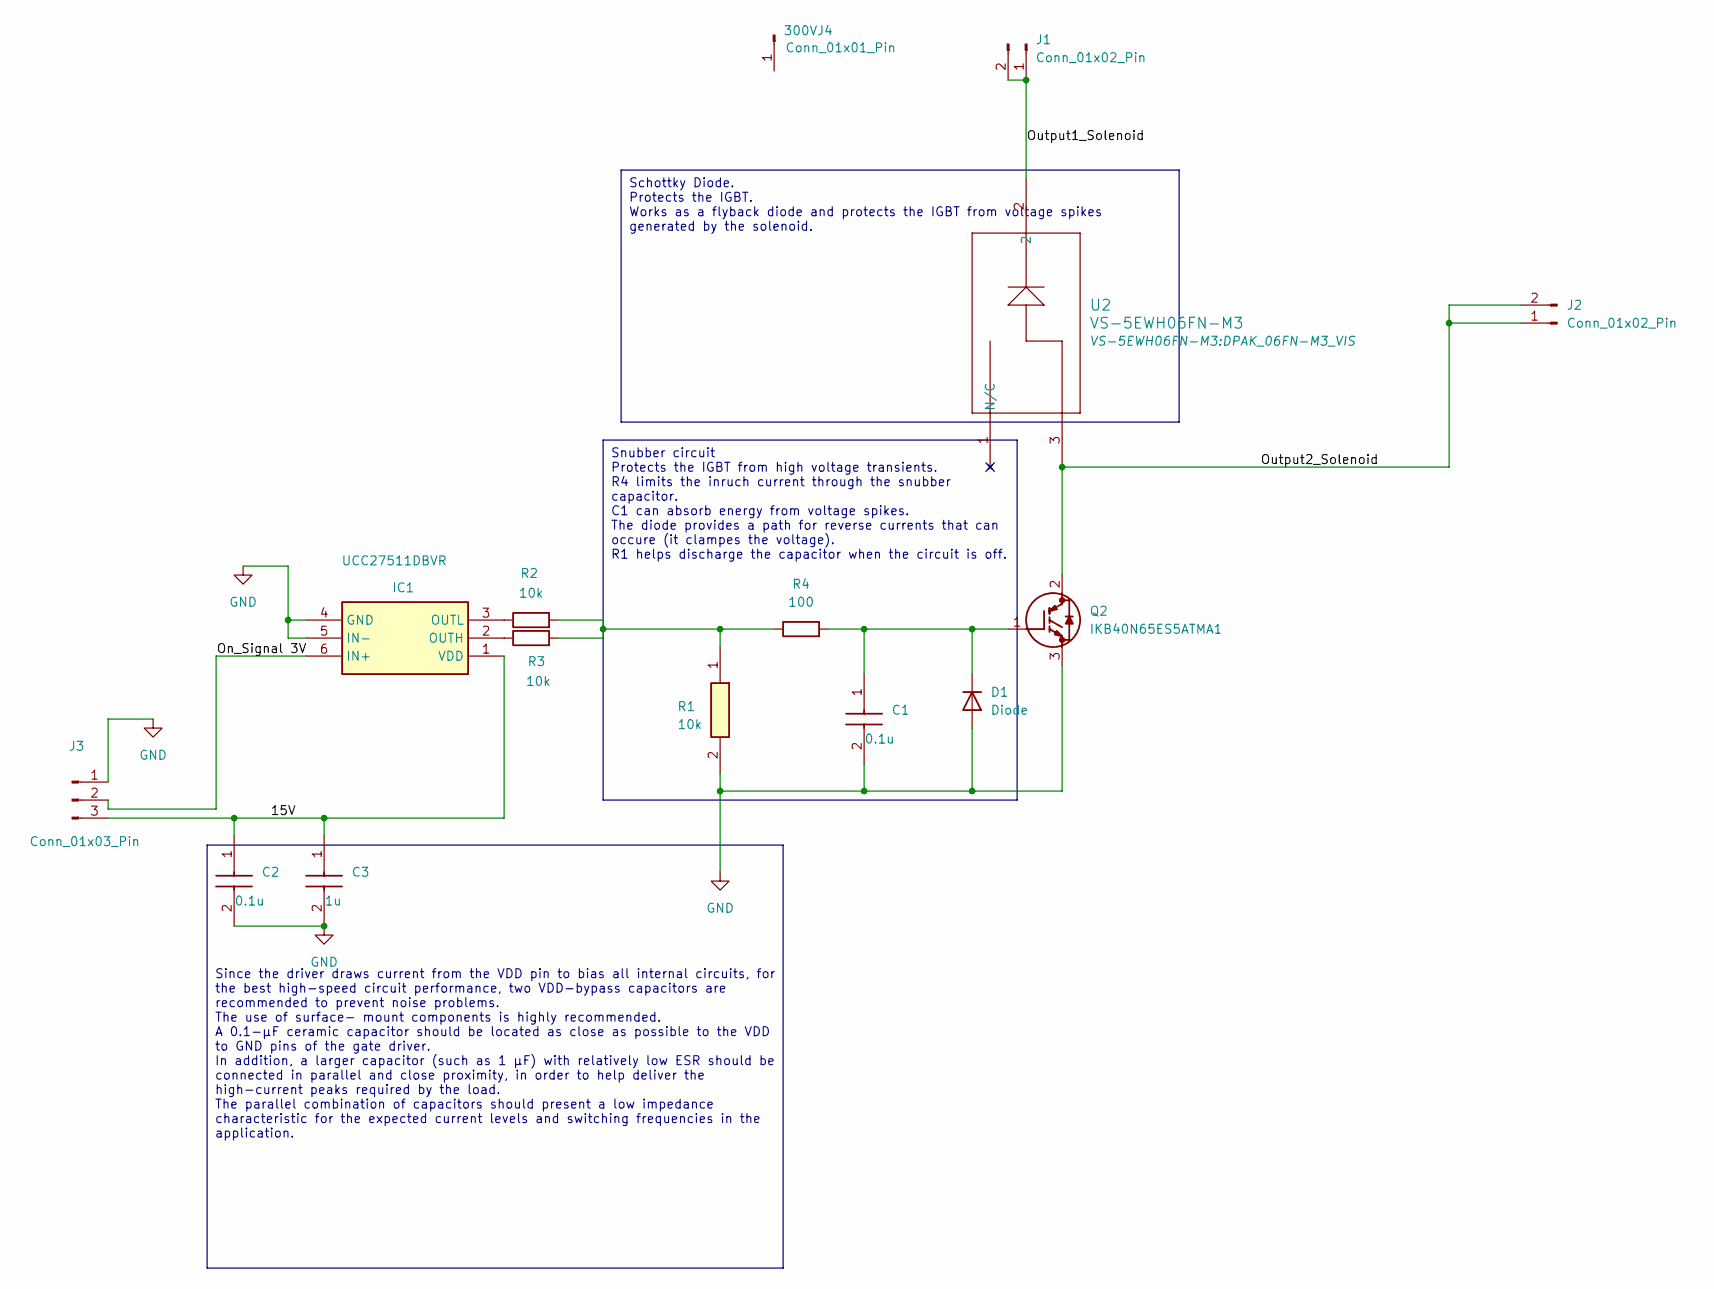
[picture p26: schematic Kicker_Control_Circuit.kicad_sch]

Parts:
300VJ4: Conn_01x01_Pin; PinHeader_1x01_P2.54mm_Vertical
C1, C2: 0.1u; C_0805_2012Metric_Pad1.18x1.45mm_HandSolder; Mouser Part Number 871-B32671P6104K000
C3: 1u; C_0805_2012Metric_Pad1.18x1.45mm_HandSolder; Mouser Part Number 871-B32671P6104K000
D1: Diode; D_SMC
IC1: UCC27511DBVR; BTS141TCBUMA1; Mouser Part Number 595-UCC27511DBVR
J1, J2: Conn_01x02_Pin; PinHeader_1x02_P2.54mm_Vertical
J3: Conn_01x03_Pin; PinHeader_1x03_P2.54mm_Vertical
Q2: IKB40N65ES5ATMA1; BTS141TCBUMA1; Mouser Part Number 726-IKB40N65ES5ATMA1
R1: 10k; R_1210_3225Metric; Mouser Part Number 71-CRCW121010K0JNAIF
R2, R3: 10k; R_1210_3225Metric
R4: 100; R_2010_5025Metric
U2: VS-5EWH06FN-M3; DPAK_06FN-M3_VIS

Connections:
/15V: C2.1, C3.1, IC1.1 (VDD), J3.3
/On_Signal 3V: IC1.6 (IN+), J3.2
/Output1_Solenoid: J1.1, J1.2, U2.2
/Output2_Solenoid: J2.1, J2.2, Q2.2 (C), U2.3
GND: C1.2, C2.2, C3.2, D1.2 (A), IC1.4 (GND), IC1.5 (IN-), J3.1, Q2.3 (E), R1.2
unnamed: C1.1, D1.1 (K), Q2.1 (G), R4.2
unnamed: IC1.2 (OUTH), R3.1
unnamed: IC1.3 (OUTL), R2.1
unnamed: R1.1, R2.2, R3.2, R4.1

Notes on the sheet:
Snubber circuit Protects the IGBT from high voltage transients. R4 limits the inruch current through the snubber capacitor. C1 can absorb energy from voltage spikes. The diode provides a path for reverse currents that can occure (it clampes the voltage). R1 helps discharge the capacitor when the ci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
Since the driver draws current from the VDD pin to bias all internal circuits, for the best high-speed circuit performance, two VDD-bypass capacitors are recommended to prevent noise problems. The use of surface- mount components is highly recommended. A 0.1-μF ceramic capacitor should be located a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
Schottky Diode. Protects the IGBT. Works as a flyback diode and protects the IGBT from voltage spikes generated by the solenoid.

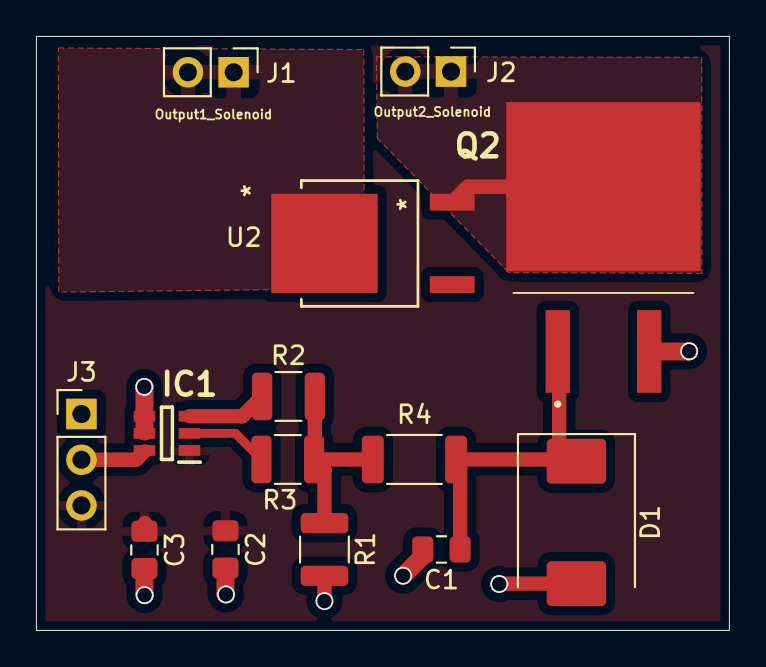
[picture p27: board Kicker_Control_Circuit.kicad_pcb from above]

Board: 2 copper layers, 38.5 x 33.0 mm, 14 parts (0 on the bottom side), 9 nets.

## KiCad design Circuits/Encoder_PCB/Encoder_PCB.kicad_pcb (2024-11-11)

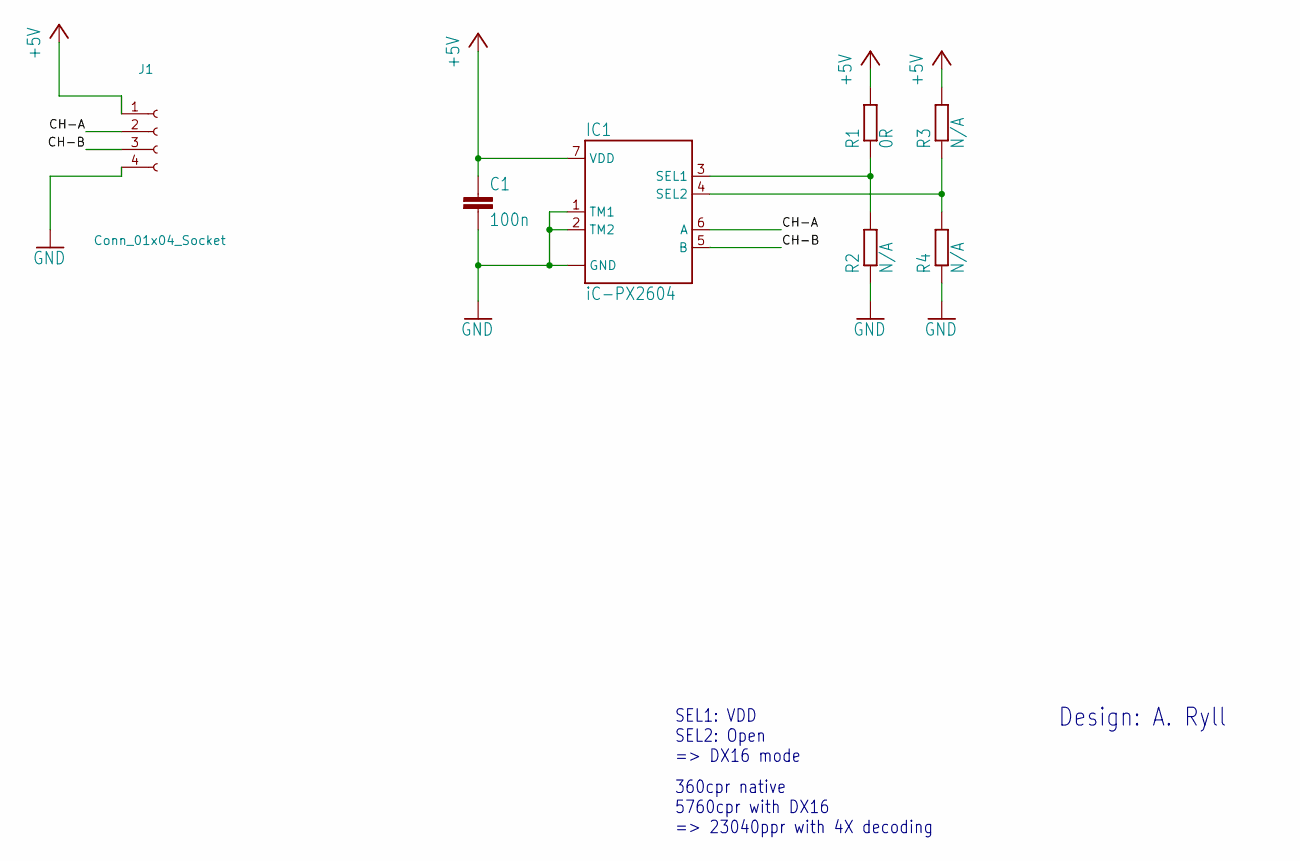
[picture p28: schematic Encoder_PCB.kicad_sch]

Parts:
C1: 100n; C_0603_1608Metric
IC1: iC-PX2604; ODFN8-3X3
J1: Conn_01x04_Socket; PinSocket_1x04_P2.54mm_Vertical
R1: 0R; R_0603_1608Metric
R2, R3, R4: N/A; R_0603_1608Metric

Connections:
+5V: C1.1, IC1.7 (VDD), J1.1, R1.2, R3.2
/CH-A: IC1.6 (A), J1.2
/CH-B: IC1.5 (B), J1.3
GND: C1.2, IC1.1 (TM1), IC1.2 (TM2), IC1.8 (GND), IC1.BP (GND), J1.4, R2.1, R4.1
unnamed: IC1.3 (SEL1), R1.1, R2.2
unnamed: IC1.4 (SEL2), R3.1, R4.2

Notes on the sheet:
360cpr native 5760cpr with DX16 => 23040ppr with 4X decoding
Design: A. Ryll
SEL1: VDD SEL2: Open => DX16 mode

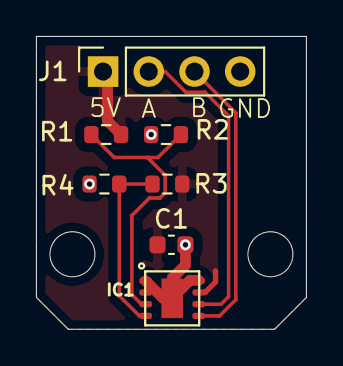
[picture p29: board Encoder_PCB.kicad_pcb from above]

Board: 2 copper layers, 15.0 x 16.3 mm, 7 parts (0 on the bottom side), 6 nets.

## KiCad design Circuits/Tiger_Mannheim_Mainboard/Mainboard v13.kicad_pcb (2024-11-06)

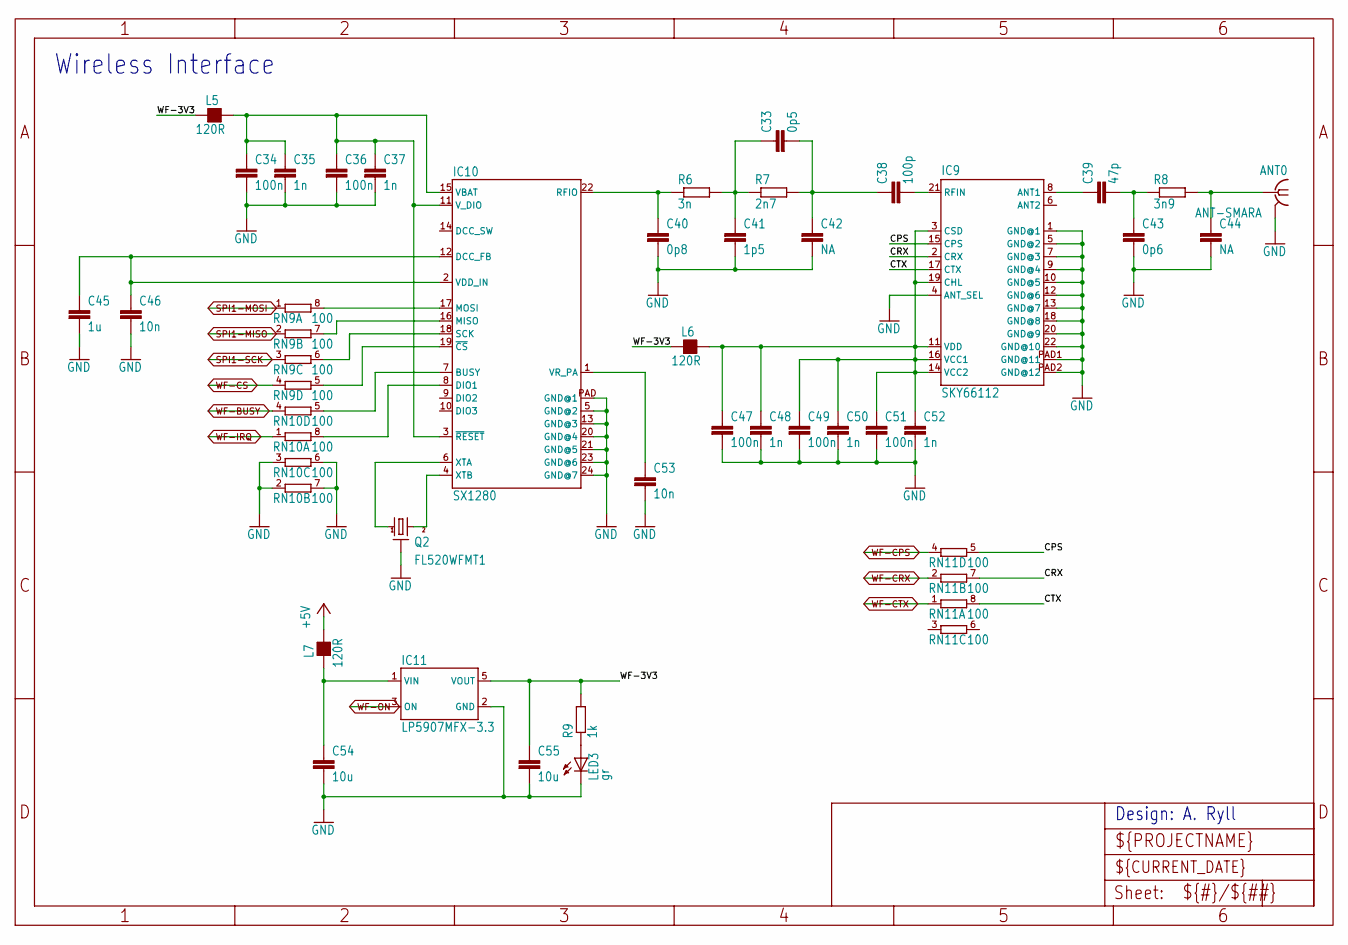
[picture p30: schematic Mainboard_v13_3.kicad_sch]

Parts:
ANT0: ANT-SMARA; ANT-SMA-RA
C33: 0p5; C0402
C34, C36, C47, C49, C51: 100n; C0603
C35, C37, C48, C50, C52: 1n; C0603
C38: 100p; C0402
C39: 47p; C0402
C40: 0p8; C0402
C41: 1p5; C0402
C42, C44: NA; C0402
C43: 0p6; C0402
C45: 1u; C0603
C46, C53: 10n; C0603
C54, C55: 10u; C0603
IC9: SKY66112; SMCM-22
IC10: SX1280; QFN24L
IC11: LP5907MFX-3.3; SOT23-5L
L5, L6, L7: 120R; L0603
LED3: gr; CHIP-LED0603
Q2: FL520WFMT1; CRYSTAL-7M
R6: 3n; R0402
R7: 2n7; R0402
R8: 3n9; R0402
R9: 1k; R0603
RN9, RN10, RN11: 100; EXB28V

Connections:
+5V: L7.2; also elsewhere on the board
CPS: IC9.15 (CPS), RN11.5 (2)
CRX: IC9.2 (CRX), RN11.7 (2)
CTX: IC9.17 (CTX), RN11.8 (2)
GND: ANT0.GND1 (GND), ANT0.GND2 (GND), ANT0.GND3 (GND), ANT0.GND4 (GND), C34.2, C35.2, C36.2, C37.2, C40.2, C41.2, C42.2, C43.2, C44.2, C45.2, C46.2, C47.2, C48.2, C49.2, C50.2, C51.2, C52.2, C53.2, C54.2, C55.2, IC9.1 (GND@1), IC9.4 (ANT_SEL), IC9.5 (GND@2), IC9.7 (GND@3), IC9.9 (GND@4), IC9.10 (GND@5), IC9.12 (GND@6), IC9.13 (GND@7), IC9.18 (GND@8), IC9.20 (GND@9), IC9.22 (GND@10), IC9.PAD1 (GND@11), IC9.PAD2 (GND@12), IC10.5 (GND@2), IC10.13 (GND@3), IC10.20 (GND@4), IC10.21 (GND@5), IC10.23 (GND@6), IC10.24 (GND@7), IC10.PAD (GND@1), IC11.2 (GND), LED3.C, Q2.2 (GND1), Q2.4 (GND1), RN10.2 (1), RN10.3 (1), RN10.6 (2), RN10.7 (2); also elsewhere on the board
unnamed: LED3.A, R9.1
unnamed: C54.1, IC11.1 (VIN), L7.1
unnamed: IC10.17 (MOSI), RN9.8 (2)
unnamed: IC10.16 (MISO), RN9.7 (2)
unnamed: IC10.18 (SCK), RN9.6 (2)
unnamed: IC10.19 (~CS), RN9.5 (2)
unnamed: IC10.7 (BUSY), RN10.5 (2)
unnamed: IC10.8 (DIO1), RN10.8 (2)
unnamed: IC10.4 (XTB), Q2.3 (2)
unnamed: IC10.6 (XTA), Q2.1
unnamed: C45.1, C46.1, IC10.2 (VDD_IN), IC10.12 (DCC_FB)
unnamed: C53.1, IC10.1 (VR_PA)
unnamed: C38.2, IC9.21 (RFIN)
unnamed: C33.1, C41.1, R6.2, R7.1
unnamed: C33.2, C38.1, C42.1, R7.2
unnamed: C40.1, IC10.22 (RFIO), R6.1
unnamed: C39.1, IC9.8 (ANT1)
unnamed: C39.2, C43.1, R8.1
unnamed: ANT0.C (1), C44.1, R8.2
SPI1-MISO: RN9.2 (1); also elsewhere on the board
SPI1-MOSI: RN9.1; also elsewhere on the board
SPI1-SCK: RN9.3 (1); also elsewhere on the board
WF-3V3: C55.1, IC11.5 (VOUT), L5.1, L6.1, R9.2
WF-BUSY: RN10.4 (1); also elsewhere on the board
WF-CPS: RN11.4 (1); also elsewhere on the board
WF-CRX: RN11.2 (1); also elsewhere on the board
WF-CS: RN9.4 (1); also elsewhere on the board
WF-CTX: RN11.1; also elsewhere on the board
WF-IRQ: RN10.1; also elsewhere on the board
WF-ON: IC11.3 (ON); also elsewhere on the board
WF_3V3FEM: C47.1, C48.1, C49.1, C50.1, C51.1, C52.1, IC9.3 (CSD), IC9.11 (VDD), IC9.14 (VCC2), IC9.16 (VCC1), IC9.19 (CHL), L6.2
WF_3V3SX: C34.1, C35.1, C36.1, C37.1, IC10.3 (~RESET), IC10.11 (V_DIO), IC10.15 (VBAT), L5.2

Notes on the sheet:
Wireless Interface
Design: A. Ryll

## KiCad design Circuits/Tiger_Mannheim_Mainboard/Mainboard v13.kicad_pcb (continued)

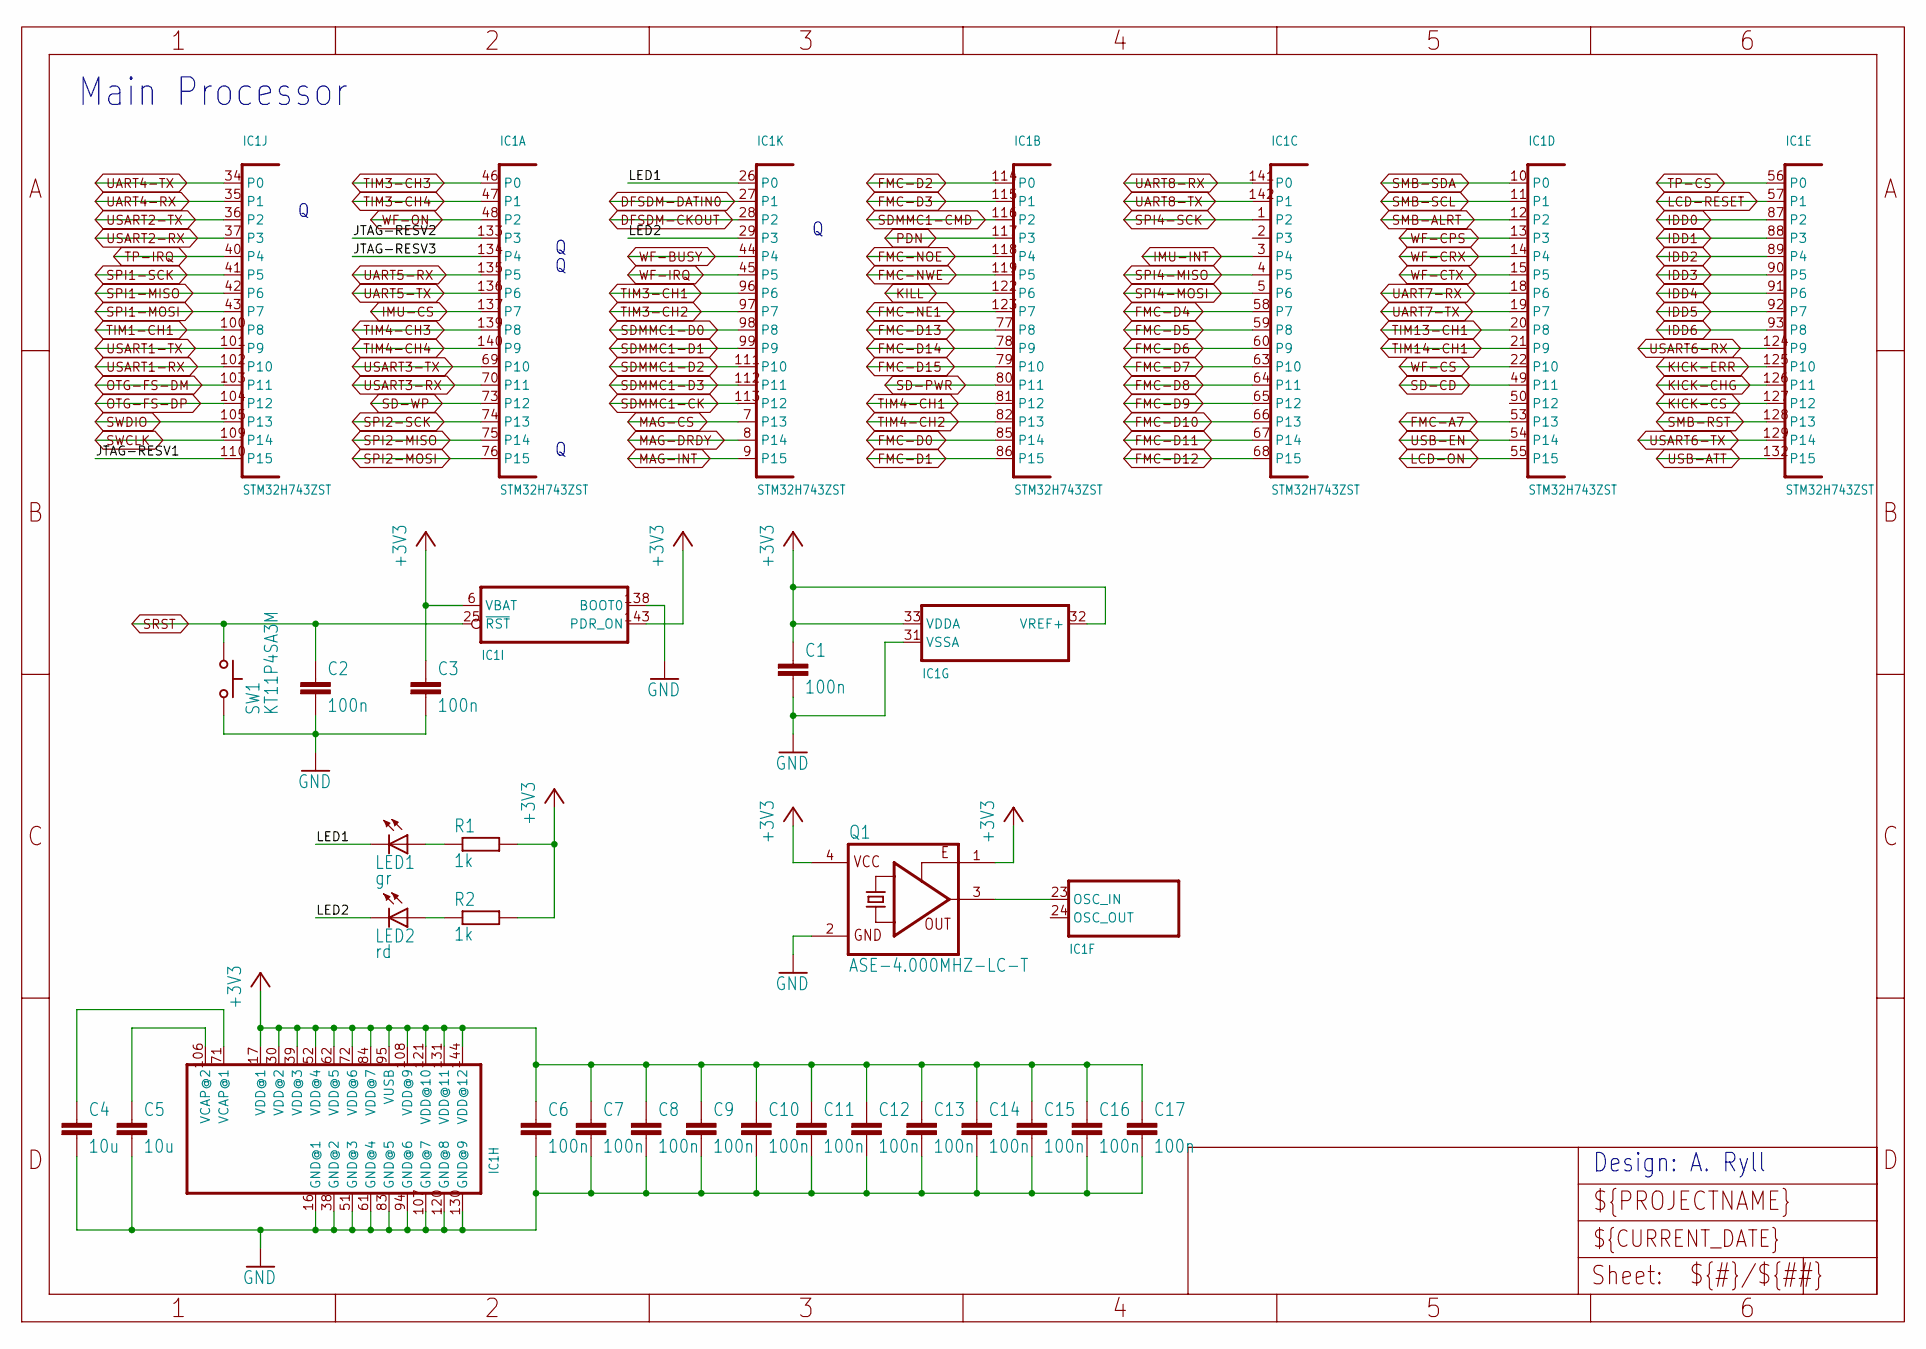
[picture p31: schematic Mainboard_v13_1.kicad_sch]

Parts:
C1, C2, C3, C6, C7, C8, C9, C10, C11, C12, C13, C14, C15, C16, C17: 100n; C0603
C4, C5: 10u; C0603
IC1: STM32H743ZST; LQFP144-ST
LED1: gr; CHIP-LED0603
LED2: rd; CHIP-LED0603
Q1: ASE-4.000MHZ-LC-T; OSCI-ASE
R1, R2: 1k; R0603
SW1: KT11P4SA3M; BUTTON4

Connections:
+3V3: C1.1, C3.1, C6.1, C7.1, C8.1, C9.1, C10.1, C11.1, C12.1, C13.1, C14.1, C15.1, C16.1, C17.1, IC1.6 (VBAT), IC1.17 (VDD@1), IC1.30 (VDD@2), IC1.32 (VREF+), IC1.33 (VDDA), IC1.39 (VDD@3), IC1.52 (VDD@4), IC1.62 (VDD@5), IC1.72 (VDD@6), IC1.84 (VDD@7), IC1.95 (VUSB), IC1.108 (VDD@9), IC1.121 (VDD@10), IC1.131 (VDD@11), IC1.143 (PDR_ON), IC1.144 (VDD@12), Q1.1 (OE), Q1.4 (VCC), R1.2, R2.2; also elsewhere on the board
DFSDM-CKOUT: IC1.28 (P2); also elsewhere on the board
DFSDM-DATIN0: IC1.27 (P1); also elsewhere on the board
FMC-A7: IC1.53 (P13); also elsewhere on the board
FMC-D0: IC1.85 (P14); also elsewhere on the board
FMC-D1: IC1.86 (P15); also elsewhere on the board
FMC-D2: IC1.114 (P0); also elsewhere on the board
FMC-D3: IC1.115 (P1); also elsewhere on the board
FMC-D4: IC1.58 (P7); also elsewhere on the board
FMC-D5: IC1.59 (P8); also elsewhere on the board
FMC-D6: IC1.60 (P9); also elsewhere on the board
FMC-D7: IC1.63 (P10); also elsewhere on the board
FMC-D8: IC1.64 (P11); also elsewhere on the board
FMC-D9: IC1.65 (P12); also elsewhere on the board
FMC-D10: IC1.66 (P13); also elsewhere on the board
FMC-D11: IC1.67 (P14); also elsewhere on the board
FMC-D12: IC1.68 (P15); also elsewhere on the board
FMC-D13: IC1.77 (P8); also elsewhere on the board
FMC-D14: IC1.78 (P9); also elsewhere on the board
FMC-D15: IC1.79 (P10); also elsewhere on the board
FMC-NE1: IC1.123 (P7); also elsewhere on the board
FMC-NOE: IC1.118 (P4); also elsewhere on the board
FMC-NWE: IC1.119 (P5); also elsewhere on the board
GND: C1.2, C2.2, C3.2, C4.2, C5.2, C6.2, C7.2, C8.2, C9.2, C10.2, C11.2, C12.2, C13.2, C14.2, C15.2, C16.2, C17.2, IC1.16 (GND@1), IC1.31 (VSSA), IC1.38 (GND@2), IC1.51 (GND@3), IC1.61 (GND@4), IC1.83 (GND@5), IC1.94 (GND@6), IC1.107 (GND@7), IC1.120 (GND@8), IC1.130 (GND@9), IC1.138 (BOOT0), Q1.2 (GND), SW1.3 (2), SW1.4 (2); also elsewhere on the board
IDD0: IC1.87 (P2); also elsewhere on the board
IDD1: IC1.88 (P3); also elsewhere on the board
IDD2: IC1.89 (P4); also elsewhere on the board
IDD3: IC1.90 (P5); also elsewhere on the board
IDD4: IC1.91 (P6); also elsewhere on the board
IDD5: IC1.92 (P7); also elsewhere on the board
IDD6: IC1.93 (P8); also elsewhere on the board
IMU-CS: IC1.137 (P7); also elsewhere on the board
IMU-INT: IC1.3 (P4); also elsewhere on the board
JTAG-RESV1: IC1.110 (P15)
JTAG-RESV2: IC1.133 (P3)
JTAG-RESV3: IC1.134 (P4)
KICK-CHG: IC1.126 (P11); also elsewhere on the board
KICK-CS: IC1.127 (P12); also elsewhere on the board
KICK-ERR: IC1.125 (P10); also elsewhere on the board
KILL: IC1.122 (P6); also elsewhere on the board
LCD-ON: IC1.55 (P15); also elsewhere on the board
LCD-RESET: IC1.57 (P1); also elsewhere on the board
LED1: IC1.26 (P0), LED1.C
LED2: IC1.29 (P3), LED2.C
MAG-CS: IC1.7 (P13); also elsewhere on the board
MAG-DRDY: IC1.8 (P14); also elsewhere on the board
MAG-INT: IC1.9 (P15); also elsewhere on the board
unnamed: LED1.A, R1.1
unnamed: LED2.A, R2.1
unnamed: IC1.23 (OSC_IN), Q1.3 (FO)
unnamed: C5.1, IC1.106 (VCAP@2)
unnamed: C4.1, IC1.71 (VCAP@1)
OTG-FS-DM: IC1.103 (P11); also elsewhere on the board
OTG-FS-DP: IC1.104 (P12); also elsewhere on the board
PDN: IC1.117 (P3); also elsewhere on the board
SD-CD: IC1.49 (P11); also elsewhere on the board
SD-PWR: IC1.80 (P11); also elsewhere on the board
SD-WP: IC1.73 (P12); also elsewhere on the board
SDMMC1-CK: IC1.113 (P12); also elsewhere on the board
SDMMC1-CMD: IC1.116 (P2); also elsewhere on the board
SDMMC1-D0: IC1.98 (P8); also elsewhere on the board
SDMMC1-D1: IC1.99 (P9); also elsewhere on the board
SDMMC1-D2: IC1.111 (P10); also elsewhere on the board
SDMMC1-D3: IC1.112 (P11); also elsewhere on the board
SMB-ALRT: IC1.12 (P2); also elsewhere on the board
SMB-RST: IC1.128 (P13); also elsewhere on the board
SMB-SCL: IC1.11 (P1); also elsewhere on the board
SMB-SDA: IC1.10 (P0); also elsewhere on the board
SPI1-MISO: IC1.42 (P6); also elsewhere on the board
SPI1-MOSI: IC1.43 (P7); also elsewhere on the board
SPI1-SCK: IC1.41 (P5); also elsewhere on the board
SPI2-MISO: IC1.75 (P14); also elsewhere on the board
SPI2-MOSI: IC1.76 (P15); also elsewhere on the board
SPI2-SCK: IC1.74 (P13); also elsewhere on the board
SPI4-MISO: IC1.4 (P5); also elsewhere on the board
SPI4-MOSI: IC1.5 (P6); also elsewhere on the board
SPI4-SCK: IC1.1 (P2); also elsewhere on the board
SRST: C2.1, IC1.25 (~RST), SW1.1, SW1.2 (1); also elsewhere on the board
SWCLK: IC1.109 (P14); also elsewhere on the board
SWDIO: IC1.105 (P13); also elsewhere on the board
TIM1-CH1: IC1.100 (P8); also elsewhere on the board
TIM3-CH1: IC1.96 (P6); also elsewhere on the board
TIM3-CH2: IC1.97 (P7); also elsewhere on the board
TIM3-CH3: IC1.46 (P0); also elsewhere on the board
TIM3-CH4: IC1.47 (P1); also elsewhere on the board
TIM4-CH1: IC1.81 (P12); also elsewhere on the board
TIM4-CH2: IC1.82 (P13); also elsewhere on the board
TIM4-CH3: IC1.139 (P8); also elsewhere on the board
TIM4-CH4: IC1.140 (P9); also elsewhere on the board
TIM13-CH1: IC1.20 (P8); also elsewhere on the board
TIM14-CH1: IC1.21 (P9); also elsewhere on the board
TP-CS: IC1.56 (P0); also elsewhere on the board
TP-IRQ: IC1.40 (P4); also elsewhere on the board
UART4-RX: IC1.35 (P1); also elsewhere on the board
UART4-TX: IC1.34 (P0); also elsewhere on the board
UART5-RX: IC1.135 (P5); also elsewhere on the board
UART5-TX: IC1.136 (P6); also elsewhere on the board
UART7-RX: IC1.18 (P6); also elsewhere on the board
UART7-TX: IC1.19 (P7); also elsewhere on the board
UART8-RX: IC1.141 (P0); also elsewhere on the board
UART8-TX: IC1.142 (P1); also elsewhere on the board
USART1-RX: IC1.102 (P10); also elsewhere on the board
USART1-TX: IC1.101 (P9); also elsewhere on the board
USART2-RX: IC1.37 (P3); also elsewhere on the board
USART2-TX: IC1.36 (P2); also elsewhere on the board
USART3-RX: IC1.70 (P11); also elsewhere on the board
USART3-TX: IC1.69 (P10); also elsewhere on the board
USART6-RX: IC1.124 (P9); also elsewhere on the board
USART6-TX: IC1.129 (P14); also elsewhere on the board
USB-ATT: IC1.132 (P15); also elsewhere on the board
USB-EN: IC1.54 (P14); also elsewhere on the board
WF-BUSY: IC1.44 (P4); also elsewhere on the board
WF-CPS: IC1.13 (P3); also elsewhere on the board
WF-CRX: IC1.14 (P4); also elsewhere on the board
WF-CS: IC1.22 (P10); also elsewhere on the board
WF-CTX: IC1.15 (P5); also elsewhere on the board
WF-IRQ: IC1.45 (P5); also elsewhere on the board
WF-ON: IC1.48 (P2); also elsewhere on the board

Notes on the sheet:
Main Processor
Design: A. Ryll


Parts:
C18, C19, C21, C24, C26, C27, C29, C30, C31: 100n; C0603
C20, C22, C23, C25, C28, C32: 10u; C0603
IC2, IC6: STMPS2151STR; SOT23-5
IC3: LT24
IC4, IC5: MP34DT05; HCLGA4
IC7: ICM-20689; QFN24-4X4-P
IC8: LIS3MDL; VFLGA-12
L1, L2, L3, L4: 120R; L0603
R3, R4: 10k; R0603
RN1, RN2, RN3, RN4, RN5, RN6, RN7, RN8, RN12: 100; EXB28V
SD0: SDCARD
USB0: USBATE; USBA-TE

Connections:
+3V3: C22.1, C23.1, C26.1, C30.1, IC4.1 (VDD), IC4.2 (LR), IC5.1 (VDD), IC7.8 (VDDIO), IC8.6 (VDDIO), L1.2, L2.2, L3.2, L4.2; also elsewhere on the board
+5V: C18.1, C24.1, IC3.11 (VCC5), IC6.5 (IN); also elsewhere on the board
DFSDM-CKOUT: IC4.3 (CLK), IC5.3 (CLK); also elsewhere on the board
DFSDM-DATIN0: IC4.4 (DOUT), IC5.4 (DOUT); also elsewhere on the board
FMC-A7: IC3.15 (RS); also elsewhere on the board
FMC-D0: IC3.9 (D0); also elsewhere on the board
FMC-D1: IC3.8 (D1); also elsewhere on the board
FMC-D2: IC3.7 (D2); also elsewhere on the board
FMC-D3: IC3.6 (D3); also elsewhere on the board
FMC-D4: IC3.16 (D4); also elsewhere on the board
FMC-D5: IC3.17 (D5); also elsewhere on the board
FMC-D6: IC3.18 (D6); also elsewhere on the board
FMC-D7: IC3.19 (D7); also elsewhere on the board
FMC-D8: IC3.20 (D8); also elsewhere on the board
FMC-D9: IC3.21 (D9); also elsewhere on the board
FMC-D10: IC3.22 (D10); also elsewhere on the board
FMC-D11: IC3.23 (D11); also elsewhere on the board
FMC-D12: IC3.24 (D12); also elsewhere on the board
FMC-D13: IC3.25 (D13); also elsewhere on the board
FMC-D14: IC3.26 (D14); also elsewhere on the board
FMC-D15: IC3.27 (D15); also elsewhere on the board
FMC-NE1: IC3.28 (CS); also elsewhere on the board
FMC-NOE: IC3.13 (RD); also elsewhere on the board
FMC-NWE: IC3.14 (WR); also elsewhere on the board
GND: C18.2, C19.2, C20.2, C21.2, C22.2, C23.2, C24.2, C25.2, C26.2, C27.2, C28.2, C29.2, C30.2, C31.2, C32.2, IC2.2 (GND), IC3.12 (GND@1), IC3.30 (GND@2), IC4.G1 (GND), IC4.G2 (GND), IC4.G3 (GND), IC4.G4 (GND), IC5.2 (LR), IC5.G1 (GND), IC5.G2 (GND), IC5.G3 (GND), IC5.G4 (GND), IC6.2 (GND), IC7.11 (FSYNC), IC7.18 (GND), IC8.2 (RSV1), IC8.3 (GND), IC8.12 (RSV2), R3.2, R4.1, RN6.4 (1), RN6.5 (2), RN8.2 (1), RN8.3 (1), RN12.2 (1), RN12.3 (1), RN12.6 (2), RN12.7 (2), SD0.3 (GND@1), SD0.6 (GND@2), SD0.COM1 (COM@1), SD0.COM2 (COM@2), SD0.COM3 (COM@3), SD0.COM4 (COM@4), USB0.4 (GND), USB0.MNT1 (S@1), USB0.MNT2 (S@2); also elsewhere on the board
IMU-CS: RN6.1; also elsewhere on the board
IMU-INT: RN12.4 (1); also elsewhere on the board
LCD-ON: RN4.5 (2); also elsewhere on the board
LCD-RESET: RN4.8 (2); also elsewhere on the board
MAG-CS: RN7.2 (1); also elsewhere on the board
MAG-DRDY: RN8.4 (1); also elsewhere on the board
MAG-INT: RN8.1; also elsewhere on the board
unnamed: IC8.10 (~CS), RN7.7 (2)
unnamed: IC8.1 (SCL/SCLK), RN7.5 (2)
unnamed: IC8.11 (SDA/MOSI), RN7.6 (2)
unnamed: IC8.9 (SA1/MISO), RN7.8 (2)
unnamed: IC8.7 (INT), RN8.8 (2)
unnamed: IC8.8 (DRDY), RN8.5 (2)
unnamed: C29.1, IC8.4 (C1)
unnamed: C31.1, C32.1, IC8.5 (VDD), L4.1
unnamed: IC7.12 (INT), RN12.5 (2)
unnamed: C19.1, IC3.29 (VCC3.3), L1.1
unnamed: IC3.38 (RESET), RN4.1
unnamed: IC3.40 (LCD_ON), RN4.4 (1)
unnamed: IC3.1 (TP_IRQ), RN1.2 (1)
unnamed: IC3.39 (TP_CS), RN4.3 (1)
unnamed: IC3.5 (TP_CLK), RN1.4 (1)
unnamed: IC3.2 (TP_DOUT), RN1.1
unnamed: IC3.4 (TP_DIN), RN1.3 (1)
unnamed: RN2.7 (2), SD0.8 (D1)
unnamed: RN2.8 (2), SD0.7 (D0)
unnamed: RN3.5 (2), SD0.5 (CLK)
unnamed: RN3.6 (2), SD0.2 (CMD)
unnamed: RN3.8 (2), SD0.9 (D2)
unnamed: RN3.7 (2), SD0.1 (D3)
unnamed: RN2.6 (2), SD0.CD
unnamed: RN2.5 (2), SD0.WP
unnamed: C20.1, C21.1, IC2.5 (IN), L2.1
unnamed: IC6.1 (OUT), USB0.1 (+5V)
unnamed: RN5.5 (2), USB0.2 (D-)
unnamed: RN5.8 (2), USB0.3 (D+)
unnamed: IC7.9 (AD0/SDO), RN12.8 (2)
unnamed: C25.1, IC7.10 (REGOUT)
unnamed: C27.1, C28.1, IC7.13 (VDD), L3.1
unnamed: IC7.24 (SDA/SDI), RN6.6 (2)
unnamed: IC7.23 (SCL/SCLK), RN6.7 (2)
unnamed: IC7.22 (~CS), RN6.8 (2)
OTG-FS-DM: RN5.4 (1); also elsewhere on the board
OTG-FS-DP: RN5.1; also elsewhere on the board
SD-CD: RN2.3 (1); also elsewhere on the board
SD-PWR: IC2.4 (EN), R3.1; also elsewhere on the board
SD-WP: RN2.4 (1); also elsewhere on the board
SDMMC1-CK: RN3.4 (1); also elsewhere on the board
SDMMC1-CMD: RN3.3 (1); also elsewhere on the board
SDMMC1-D0: RN2.1; also elsewhere on the board
SDMMC1-D1: RN2.2 (1); also elsewhere on the board
SDMMC1-D2: RN3.1; also elsewhere on the board
SDMMC1-D3: RN3.2 (1); also elsewhere on the board
SD_PWR: IC2.1 (OUT), SD0.4 (VDD)
SPI4-MISO: RN1.8 (2), RN7.1, RN12.1; also elsewhere on the board
SPI4-MOSI: RN1.6 (2), RN6.3 (1), RN7.3 (1); also elsewhere on the board
SPI4-SCK: RN1.5 (2), RN6.2 (1), RN7.4 (1); also elsewhere on the board
TP-CS: RN4.6 (2); also elsewhere on the board
TP-IRQ: RN1.7 (2); also elsewhere on the board
USB-EN: IC6.4 (EN), R4.2; also elsewhere on the board

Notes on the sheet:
2mA
IMU
Design: A. Ryll
USB Host
SD Card
Magnetometer
Microphones
LCD


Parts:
C56, C58: 33u; C1206; VOLTAGE 25V
C57, C59: 100n; C0603
IC12: LT3080ST; SOT223
IDD0: TE-FPC-1MM-8V; TE-1734248-8
L8: 470R; L1206
LED4: gr; CHIP-LED0603
LEDS0: TE-FPC-1MM-10H; TE-1-84952-0
PAD1, PAD2, PAD3: WIREPAD5,4/3,0; 5,4_3,0
PWR0: 4-1734742-0; TE-4-1734592-0
R10: 1k; R0603
R11: 330k; R0603
SW2: KT11P4SA3M; KT11

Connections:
+3V3: C58.1, IC12.2 (OUT), IC12.4 (OUT), R10.2; also elsewhere on the board
+5V: L8.1, LEDS0.1, PWR0.1, PWR0.2; also elsewhere on the board
BTN: PWR0.18, SW2.1
GND: C56.2, C57.2, C58.2, C59.2, LED4.C, LEDS0.10, PAD1.1, PAD1.2, PAD2.1, PAD2.2, PAD3.1, PAD3.2, PWR0.39, PWR0.40, R11.1, SW2.2; also elsewhere on the board
IDD0: IDD0.A2, IDD0.B2; also elsewhere on the board
IDD1: IDD0.A3, IDD0.B3; also elsewhere on the board
IDD2: IDD0.A4, IDD0.B4; also elsewhere on the board
IDD3: IDD0.A5, IDD0.B5; also elsewhere on the board
IDD4: IDD0.A6, IDD0.B6; also elsewhere on the board
IDD5: IDD0.A7, IDD0.B7; also elsewhere on the board
IDD6: IDD0.A8, IDD0.B8; also elsewhere on the board
KICK-CHG: PWR0.35; also elsewhere on the board
KICK-CS: PWR0.31; also elsewhere on the board
KICK-ERR: PWR0.38; also elsewhere on the board
KILL: PWR0.17; also elsewhere on the board
unnamed: C59.1, IC12.1 (SET), R11.2
unnamed: LED4.A, R10.1
unnamed: C56.1, C57.1, IC12.3 (IN), L8.2
PDN: PWR0.19; also elsewhere on the board
SMB-ALRT: PWR0.13; also elsewhere on the board
SMB-RST: PWR0.12; also elsewhere on the board
SMB-SCL: PWR0.15; also elsewhere on the board
SMB-SDA: PWR0.14; also elsewhere on the board
SPI2-MISO: PWR0.33; also elsewhere on the board
SPI2-MOSI: PWR0.32; also elsewhere on the board
SPI2-SCK: PWR0.34; also elsewhere on the board
SRST: PWR0.28; also elsewhere on the board
SWCLK: PWR0.26; also elsewhere on the board
SWDIO: PWR0.27; also elsewhere on the board
TIM1-CH1: PWR0.16; also elsewhere on the board
TIM3-CH1: LEDS0.2; also elsewhere on the board
TIM3-CH2: LEDS0.3; also elsewhere on the board
TIM3-CH3: LEDS0.4; also elsewhere on the board
TIM3-CH4: LEDS0.5; also elsewhere on the board
TIM4-CH1: LEDS0.6; also elsewhere on the board
TIM4-CH2: LEDS0.7; also elsewhere on the board
TIM4-CH3: LEDS0.8; also elsewhere on the board
TIM4-CH4: LEDS0.9; also elsewhere on the board
TIM13-CH1: PWR0.36; also elsewhere on the board
TIM14-CH1: PWR0.37; also elsewhere on the board
UART4-RX: PWR0.9; also elsewhere on the board
UART4-TX: PWR0.10; also elsewhere on the board
UART5-RX: PWR0.5; also elsewhere on the board
UART5-TX: PWR0.6; also elsewhere on the board
UART7-RX: PWR0.7; also elsewhere on the board
UART7-TX: PWR0.8; also elsewhere on the board
UART8-RX: PWR0.3; also elsewhere on the board
UART8-TX: PWR0.4; also elsewhere on the board
USART1-RX: PWR0.30; also elsewhere on the board
USART1-TX: PWR0.29; also elsewhere on the board
USART2-RX: PWR0.23; also elsewhere on the board
USART2-TX: PWR0.22; also elsewhere on the board
USART3-RX: PWR0.21; also elsewhere on the board
USART3-TX: PWR0.20; also elsewhere on the board
USART6-RX: PWR0.24; also elsewhere on the board
USART6-TX: PWR0.25; also elsewhere on the board
USB-ATT: PWR0.11; also elsewhere on the board

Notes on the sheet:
Max output: 800mA (110°C)
LDO 3.3V
Connectors
Kicker
DIS1
DIS2
Design: A. Ryll
Buzzer



Board: 4 copper layers, 80.0 x 85.0 mm, 118 parts (3 on the bottom side), 181 nets.

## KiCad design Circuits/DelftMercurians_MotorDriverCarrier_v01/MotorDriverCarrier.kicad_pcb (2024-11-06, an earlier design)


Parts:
C0: C_Polarized; CP_Radial_D8.0mm_P3.50mm
C1: 0.1u; C_0603_1608Metric_Pad1.08x0.95mm_HandSolder
D1, D2, D3, D5: LED; LED_0603_1608Metric_Pad1.05x0.95mm_HandSolder
D4: BZV55C15; D_MiniMELF
H1: MountingHole; MountingHole_3.2mm_M3_ISO14580
H2: VIN; MountingHole_3.2mm_M3_ISO7380_Pad_TopOnly
H3: PGND; MountingHole_3.2mm_M3_ISO7380_Pad_TopOnly
J1: Motor_Encoder; PinHeader_2x05_P1.27mm_Vertical
J2: Driver_Encoder; PinHeader_1x05_P1.27mm_Vertical
J3, J4, J5, J6, J7: Conn_01x01_Male; PinHeader_1x01_P2.54mm_Vertical
J8: CAN_1; JST_GH_SM03B-GHS-TB_1x03-1MP_P1.25mm_Horizontal
J9: CAN_2; JST_GH_SM03B-GHS-TB_1x03-1MP_P1.25mm_Horizontal
J10: Edge_Motor; CustomEdge_Motor3
J11: Edge_Power; CustomEdge_Power2
J12: UART_1; JST_GH_SM04B-GHS-TB_1x04-1MP_P1.25mm_Horizontal
J13: Edge_UART; CustomEdge_UART5
J14: Edge_CAN; CustomEdge_CAN4
JP1: Jumper_2_Bridged; SolderJumper-2_P1.3mm_Open_TrianglePad1.0x1.5mm
JP2, JP3: Jumper_2_Open; SolderJumper-2_P1.3mm_Open_RoundedPad1.0x1.5mm
Q1: 671-1100; SOT-223-3_TabPin2
R1, R2: 1k5; R_0603_1608Metric_Pad0.98x0.95mm_HandSolder
R3, R4, R5: R10k; R_0603_1608Metric_Pad0.98x0.95mm_HandSolder
R6: 11k; R_0603_1608Metric_Pad0.98x0.95mm_HandSolder
R7: 1k8; R_0603_1608Metric_Pad0.98x0.95mm_HandSolder
U1: UA9637; SOIC-8_3.9x4.9mm_P1.27mm

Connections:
+5V: C1.1, J1.10, J4.1, J14.4, JP2.1 (A), R1.1, R3.1, U1.1 (VCC)
+24V: C0.1, D4.1 (K), J11.2, Q1.3 (S)
/Vin: H2.1, Q1.2 (D), Q1.4 (D), R6.1
A: J2.5, U1.2 (OUT)
A+: J1.8, U1.8 (IN+)
A-: J1.9, U1.7 (IN-)
B: J2.4, U1.3 (OUT)
B+: J1.6, U1.6 (IN+)
B-: J1.7, U1.5 (IN-)
CAN_H: J8.3, J9.3, J14.2
CAN_L: J8.2, J9.2, J14.3
ENCODER_HOUSING: J1.2
GND: C1.2, D1.1 (K), D2.1 (K), J1.1, J6.1, J8.1, J9.1, J14.1, JP1.2 (B), JP3.1 (A), R5.2, U1.4 (GND)
GNDPWR: C0.2, D3.1 (K), D5.2 (A), H3.1, J11.1, J12.MP (MountPin), JP1.1 (A), R7.2
H1: J1.5
H2: J1.4
H3: J1.3
MOTOR_A: J10.1
MOTOR_B: J10.2
MOTOR_C: J10.3
unnamed: D1.2 (A), R1.2
unnamed: D2.2 (A), R2.2
unnamed: D3.2 (A), D5.1 (K), R6.2
unnamed: D4.2 (A), Q1.1 (G), R7.1
unnamed: J2.1, JP3.2 (B)
unnamed: J2.2, JP2.2 (B)
unnamed: J5.1, R3.2, R4.1
unnamed: J7.1, R4.2, R5.1
PWM: J3.1, J13.2
UART_GND: J12.4, J13.1
UART_RX: J12.3, J13.3
UART_TX: J12.2, J13.4, R2.1
UART_VCC: J12.1, J13.5
Z: J2.3

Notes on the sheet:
Daughterboard
CAN Connectors
ID Select
UART Connector
Internals
Encoder Connector
Status LEDs
Line Receiver
Ground Interconnect
Power Input
Outputs
Inputs

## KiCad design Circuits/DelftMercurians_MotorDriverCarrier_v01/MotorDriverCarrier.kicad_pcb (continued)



Board: 2 copper layers, 46.2 x 61.4 mm, 36 parts (10 on the bottom side), 26 nets.

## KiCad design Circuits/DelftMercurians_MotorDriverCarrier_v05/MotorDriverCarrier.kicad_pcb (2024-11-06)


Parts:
C1: 0.1u; C_0603_1608Metric_Pad1.08x0.95mm_HandSolder
D1, D2, D3: LED; LED_0603_1608Metric_Pad1.05x0.95mm_HandSolder
H1, H2: MountingHole; MountingHole_3.2mm_M3_ISO14580
J1: Edge_PROG; CustomEdge_PROG
J2: Driver_Encoder; PinHeader_1x05_P2.00mm_Vertical
J10: Edge_Motor; CustomEdge_Motor3_Single
J11: Edge_Power; CustomEdge_Power2
J13: Edge_UART; CustomEdge_UART5
J14: Edge_CAN; CustomEdge_CAN4
J15: Main Connector; BUS_PCIexpress_x4
JP1: Jumper_2_Bridged; SolderJumper-2_P1.3mm_Open_TrianglePad1.0x1.5mm
JP2: Jumper_2_Bridged; SolderJumper-2_P1.3mm_Bridged_RoundedPad1.0x1.5mm
R1, R2: 1k5; R_0603_1608Metric_Pad0.98x0.95mm_HandSolder
R6: 11k; R_0603_1608Metric_Pad0.98x0.95mm_HandSolder
TP1, TP2, TP3: TestPoint; TestPoint_Pad_D1.0mm
U1: UA9637; SOIC-8_3.9x4.9mm_P1.27mm

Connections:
+3.3V: J1.2
+5V: C1.1, J2.2, J14.4, J15.A12 (+5V), R1.1, U1.1 (VCC)
+24V: J11.2, J15.A4 (VCC), J15.A5 (VCC), J15.A6 (VCC), J15.B4 (VCC), J15.B5 (VCC), J15.B6 (VCC), R6.1
A: J2.5, U1.2 (OUT)
A+: J15.B15 (ENC_A+), U1.8 (IN+)
A-: J15.B16 (ENC_A-), U1.7 (IN-)
B: J2.4, U1.3 (OUT)
B+: J15.A15 (ENC_B+), U1.6 (IN+)
B-: J15.A16 (ENC_B-), U1.5 (IN-)
CAN_H: J14.3, J15.A13 (CAN_H), J15.A14 (CAN_H)
CAN_L: J14.2, J15.B13 (CAN_L), J15.B14 (CAN_L)
GNDPWR: D3.1 (K), J11.1, J15.A1 (PGND), J15.A2 (PGND), J15.A3 (PGND), J15.B1 (PGND), J15.B2 (PGND), J15.B3 (PGND), JP1.1 (A)
HALL_A: J15.A11 (HALL_A), JP2.1 (A), TP1.1
HALL_B: J15.B11 (HALL_B), TP2.1
HALL_C: J15.B10 (HALL_C), TP3.1
MOTOR_A: J10.1, J15.A28 (PHASE_A), J15.A29 (PHASE_A), J15.A30 (PHASE_A), J15.A31 (PHASE_A), J15.A32 (PHASE_A), J15.B28 (PHASE_A), J15.B29 (PHASE_A), J15.B30 (PHASE_A), J15.B31 (PHASE_A), J15.B32 (PHASE_A)
MOTOR_B: J10.2, J15.A23 (PHASE_B), J15.A24 (PHASE_B), J15.A25 (PHASE_B), J15.A26 (PHASE_B), J15.A27 (PHASE_B), J15.B23 (PHASE_B), J15.B24 (PHASE_B), J15.B25 (PHASE_B), J15.B26 (PHASE_B), J15.B27 (PHASE_B)
MOTOR_C: J10.3, J15.A18 (PHASE_C), J15.A19 (PHASE_C), J15.A20 (PHASE_C), J15.A21 (PHASE_C), J15.A22 (PHASE_C), J15.B18 (PHASE_C), J15.B19 (PHASE_C), J15.B20 (PHASE_C), J15.B21 (PHASE_C), J15.B22 (PHASE_C)
NRST: J1.5, J15.A9 (NRST)
unnamed: D1.2 (A), R1.2
unnamed: D2.2 (A), R2.2
unnamed: D3.2 (A), R6.2
OK: J13.2, R2.1
SWCLK: J1.3, J15.B9 (SWCLK)
SWDIO: J1.4, J15.A10 (SWDIO)
UART_GND: C1.2, D1.1 (K), D2.1 (K), J1.1, J2.1, J13.1, J14.1, J15.B12 (GND), JP1.2 (B), U1.4 (GND)
UART_RX: J13.3, J15.A8 (UART_RX)
UART_TX: J13.4, J15.B8 (UART_TX)
UART_VCC: J13.5
Z: J2.3, JP2.2 (B)

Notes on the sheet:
Daughterboard
Internals
Status LEDs
Line Receiver
Ground Interconnect
Power Input
Outputs
Inputs



Board: 4 copper layers, 38.2 x 58.4 mm, 22 parts (2 on the bottom side), 28 nets.

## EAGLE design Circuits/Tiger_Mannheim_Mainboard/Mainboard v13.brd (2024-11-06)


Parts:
C1, C2, C3, C6, C7, C8, C9, C10, C11, C12, C13, C14, C15, C16, C17: 100n; C0603
C4, C5: 10u; C0603
IC1: STM32H743ZST; LQFP144-ST
LED1: gr; CHIP-LED0603
LED2: rd; CHIP-LED0603
Q1: ASE-4.000MHZ-LC-T; OSCI-ASE
R1, R2: 1k; R0603
SW1: KT11P4SA3M; BUTTON4

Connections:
+3V3: C1.1, C3.1, C6.1, C7.1, C8.1, C9.1, C10.1, C11.1, C12.1, C13.1, C14.1, C15.1, C16.1, C17.1, IC1.6 (VBAT), IC1.17 (VDD), IC1.30 (VDD), IC1.32 (VREF+), IC1.33 (VDDA), IC1.39 (VDD), IC1.52 (VDD), IC1.62 (VDD), IC1.72 (VDD), IC1.84 (VDD), IC1.95 (VUSB), IC1.108 (VDD), IC1.121 (VDD), IC1.131 (VDD), IC1.143 (PDR_ON), IC1.144 (VDD), Q1.1 (OE), Q1.4 (VCC), R1.2, R2.2; also elsewhere on the board
DFSDM-CKOUT: IC1.28 (P2); also elsewhere on the board
DFSDM-DATIN0: IC1.27 (P1); also elsewhere on the board
FMC-A7: IC1.53 (P13); also elsewhere on the board
FMC-D0: IC1.85 (P14); also elsewhere on the board
FMC-D1: IC1.86 (P15); also elsewhere on the board
FMC-D2: IC1.114 (P0); also elsewhere on the board
FMC-D3: IC1.115 (P1); also elsewhere on the board
FMC-D4: IC1.58 (P7); also elsewhere on the board
FMC-D5: IC1.59 (P8); also elsewhere on the board
FMC-D6: IC1.60 (P9); also elsewhere on the board
FMC-D7: IC1.63 (P10); also elsewhere on the board
FMC-D8: IC1.64 (P11); also elsewhere on the board
FMC-D9: IC1.65 (P12); also elsewhere on the board
FMC-D10: IC1.66 (P13); also elsewhere on the board
FMC-D11: IC1.67 (P14); also elsewhere on the board
FMC-D12: IC1.68 (P15); also elsewhere on the board
FMC-D13: IC1.77 (P8); also elsewhere on the board
FMC-D14: IC1.78 (P9); also elsewhere on the board
FMC-D15: IC1.79 (P10); also elsewhere on the board
FMC-NE1: IC1.123 (P7); also elsewhere on the board
FMC-NOE: IC1.118 (P4); also elsewhere on the board
FMC-NWE: IC1.119 (P5); also elsewhere on the board
GND: C1.2, C2.2, C3.2, C4.2, C5.2, C6.2, C7.2, C8.2, C9.2, C10.2, C11.2, C12.2, C13.2, C14.2, C15.2, C16.2, C17.2, IC1.16 (GND), IC1.31 (VSSA), IC1.38 (GND), IC1.51 (GND), IC1.61 (GND), IC1.83 (GND), IC1.94 (GND), IC1.107 (GND), IC1.120 (GND), IC1.130 (GND), IC1.138 (BOOT0), Q1.2 (GND), SW1.3 (2), SW1.4 (2); also elsewhere on the board
IDD0: IC1.87 (P2); also elsewhere on the board
IDD1: IC1.88 (P3); also elsewhere on the board
IDD2: IC1.89 (P4); also elsewhere on the board
IDD3: IC1.90 (P5); also elsewhere on the board
IDD4: IC1.91 (P6); also elsewhere on the board
IDD5: IC1.92 (P7); also elsewhere on the board
IDD6: IC1.93 (P8); also elsewhere on the board
IMU-CS: IC1.137 (P7); also elsewhere on the board
IMU-INT: IC1.3 (P4); also elsewhere on the board
JTAG-RESV1: IC1.110 (P15)
JTAG-RESV2: IC1.133 (P3)
JTAG-RESV3: IC1.134 (P4)
KICK-CHG: IC1.126 (P11); also elsewhere on the board
KICK-CS: IC1.127 (P12); also elsewhere on the board
KICK-ERR: IC1.125 (P10); also elsewhere on the board
KILL: IC1.122 (P6); also elsewhere on the board
LCD-ON: IC1.55 (P15); also elsewhere on the board
LCD-RESET: IC1.57 (P1); also elsewhere on the board
LED1: IC1.26 (P0), LED1.C
LED2: IC1.29 (P3), LED2.C
MAG-CS: IC1.7 (P13); also elsewhere on the board
MAG-DRDY: IC1.8 (P14); also elsewhere on the board
MAG-INT: IC1.9 (P15); also elsewhere on the board
unnamed: LED1.A, R1.1
unnamed: LED2.A, R2.1
unnamed: IC1.23 (OSC_IN), Q1.3 (FO)
unnamed: C5.1, IC1.106 (VCAP)
unnamed: C4.1, IC1.71 (VCAP)
OTG-FS-DM: IC1.103 (P11); also elsewhere on the board
OTG-FS-DP: IC1.104 (P12); also elsewhere on the board
PDN: IC1.117 (P3); also elsewhere on the board
SD-CD: IC1.49 (P11); also elsewhere on the board
SD-PWR: IC1.80 (P11); also elsewhere on the board
SD-WP: IC1.73 (P12); also elsewhere on the board
SDMMC1-CK: IC1.113 (P12); also elsewhere on the board
SDMMC1-CMD: IC1.116 (P2); also elsewhere on the board
SDMMC1-D0: IC1.98 (P8); also elsewhere on the board
SDMMC1-D1: IC1.99 (P9); also elsewhere on the board
SDMMC1-D2: IC1.111 (P10); also elsewhere on the board
SDMMC1-D3: IC1.112 (P11); also elsewhere on the board
SMB-ALRT: IC1.12 (P2); also elsewhere on the board
SMB-RST: IC1.128 (P13); also elsewhere on the board
SMB-SCL: IC1.11 (P1); also elsewhere on the board
SMB-SDA: IC1.10 (P0); also elsewhere on the board
SPI1-MISO: IC1.42 (P6); also elsewhere on the board
SPI1-MOSI: IC1.43 (P7); also elsewhere on the board
SPI1-SCK: IC1.41 (P5); also elsewhere on the board
SPI2-MISO: IC1.75 (P14); also elsewhere on the board
SPI2-MOSI: IC1.76 (P15); also elsewhere on the board
SPI2-SCK: IC1.74 (P13); also elsewhere on the board
SPI4-MISO: IC1.4 (P5); also elsewhere on the board
SPI4-MOSI: IC1.5 (P6); also elsewhere on the board
SPI4-SCK: IC1.1 (P2); also elsewhere on the board
SRST: C2.1, IC1.25 (!RST), SW1.1, SW1.2 (1); also elsewhere on the board
SWCLK: IC1.109 (P14); also elsewhere on the board
SWDIO: IC1.105 (P13); also elsewhere on the board
TIM1-CH1: IC1.100 (P8); also elsewhere on the board
TIM3-CH1: IC1.96 (P6); also elsewhere on the board
TIM3-CH2: IC1.97 (P7); also elsewhere on the board
TIM3-CH3: IC1.46 (P0); also elsewhere on the board
TIM3-CH4: IC1.47 (P1); also elsewhere on the board
TIM4-CH1: IC1.81 (P12); also elsewhere on the board
TIM4-CH2: IC1.82 (P13); also elsewhere on the board
TIM4-CH3: IC1.139 (P8); also elsewhere on the board
TIM4-CH4: IC1.140 (P9); also elsewhere on the board
TIM13-CH1: IC1.20 (P8); also elsewhere on the board
TIM14-CH1: IC1.21 (P9); also elsewhere on the board
TP-CS: IC1.56 (P0); also elsewhere on the board
TP-IRQ: IC1.40 (P4); also elsewhere on the board
UART4-RX: IC1.35 (P1); also elsewhere on the board
UART4-TX: IC1.34 (P0); also elsewhere on the board
UART5-RX: IC1.135 (P5); also elsewhere on the board
UART5-TX: IC1.136 (P6); also elsewhere on the board
UART7-RX: IC1.18 (P6); also elsewhere on the board
UART7-TX: IC1.19 (P7); also elsewhere on the board
UART8-RX: IC1.141 (P0); also elsewhere on the board
UART8-TX: IC1.142 (P1); also elsewhere on the board
USART1-RX: IC1.102 (P10); also elsewhere on the board
USART1-TX: IC1.101 (P9); also elsewhere on the board
USART2-RX: IC1.37 (P3); also elsewhere on the board
USART2-TX: IC1.36 (P2); also elsewhere on the board
USART3-RX: IC1.70 (P11); also elsewhere on the board
USART3-TX: IC1.69 (P10); also elsewhere on the board
USART6-RX: IC1.124 (P9); also elsewhere on the board
USART6-TX: IC1.129 (P14); also elsewhere on the board
USB-ATT: IC1.132 (P15); also elsewhere on the board
USB-EN: IC1.54 (P14); also elsewhere on the board
WF-BUSY: IC1.44 (P4); also elsewhere on the board
WF-CPS: IC1.13 (P3); also elsewhere on the board
WF-CRX: IC1.14 (P4); also elsewhere on the board
WF-CS: IC1.22 (P10); also elsewhere on the board
WF-CTX: IC1.15 (P5); also elsewhere on the board
WF-IRQ: IC1.45 (P5); also elsewhere on the board
WF-ON: IC1.48 (P2); also elsewhere on the board

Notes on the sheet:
Design: A. Ryll
Main Processor


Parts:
C18, C19, C21, C24, C26, C27, C29, C30, C31: 100n; C0603
C20, C22, C23, C25, C28, C32: 10u; C0603
IC2, IC6: STMPS2151STR; SOT23-5
IC3: LT24
IC4, IC5: MP34DT05; HCLGA4
IC7: ICM-20689; QFN24-4X4-P
IC8: LIS3MDL; VFLGA-12
L1, L2, L3, L4: 120R; L0603
R3, R4: 10k; R0603
RN1, RN2, RN3, RN4, RN5, RN6, RN7, RN8, RN12: 100; EXB28V
SD: SDCARD
USB: USBATE; USBA-TE

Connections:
+3V3: C22.1, C23.1, C26.1, C30.1, IC4.1 (VDD), IC4.2 (LR), IC5.1 (VDD), IC7.8 (VDDIO), IC8.6 (VDDIO), L1.2, L2.2, L3.2, L4.2; also elsewhere on the board
+5V: C18.1, C24.1, IC3.11 (VCC5), IC6.5 (IN); also elsewhere on the board
DFSDM-CKOUT: IC4.3 (CLK), IC5.3 (CLK); also elsewhere on the board
DFSDM-DATIN0: IC4.4 (DOUT), IC5.4 (DOUT); also elsewhere on the board
FMC-A7: IC3.15 (RS); also elsewhere on the board
FMC-D0: IC3.9 (D0); also elsewhere on the board
FMC-D1: IC3.8 (D1); also elsewhere on the board
FMC-D2: IC3.7 (D2); also elsewhere on the board
FMC-D3: IC3.6 (D3); also elsewhere on the board
FMC-D4: IC3.16 (D4); also elsewhere on the board
FMC-D5: IC3.17 (D5); also elsewhere on the board
FMC-D6: IC3.18 (D6); also elsewhere on the board
FMC-D7: IC3.19 (D7); also elsewhere on the board
FMC-D8: IC3.20 (D8); also elsewhere on the board
FMC-D9: IC3.21 (D9); also elsewhere on the board
FMC-D10: IC3.22 (D10); also elsewhere on the board
FMC-D11: IC3.23 (D11); also elsewhere on the board
FMC-D12: IC3.24 (D12); also elsewhere on the board
FMC-D13: IC3.25 (D13); also elsewhere on the board
FMC-D14: IC3.26 (D14); also elsewhere on the board
FMC-D15: IC3.27 (D15); also elsewhere on the board
FMC-NE1: IC3.28 (CS); also elsewhere on the board
FMC-NOE: IC3.13 (RD); also elsewhere on the board
FMC-NWE: IC3.14 (WR); also elsewhere on the board
GND: C18.2, C19.2, C20.2, C21.2, C22.2, C23.2, C24.2, C25.2, C26.2, C27.2, C28.2, C29.2, C30.2, C31.2, C32.2, IC2.2 (GND), IC3.12 (GND), IC3.30 (GND), IC4.G1 (GND), IC4.G2 (GND), IC4.G3 (GND), IC4.G4 (GND), IC5.2 (LR), IC5.G1 (GND), IC5.G2 (GND), IC5.G3 (GND), IC5.G4 (GND), IC6.2 (GND), IC7.11 (FSYNC), IC7.18 (GND), IC8.2 (RSV1), IC8.3 (GND), IC8.12 (RSV2), R3.2, R4.1, RN6.4 (1), RN6.5 (2), RN8.2 (1), RN8.3 (1), RN12.2 (1), RN12.3 (1), RN12.6 (2), RN12.7 (2), SD.3 (GND), SD.6 (GND), SD.COM1 (COM), SD.COM2 (COM), SD.COM3 (COM), SD.COM4 (COM), USB.4 (GND), USB.MNT1 (S), USB.MNT2 (S); also elsewhere on the board
IMU-CS: RN6.1; also elsewhere on the board
IMU-INT: RN12.4 (1); also elsewhere on the board
LCD-ON: RN4.5 (2); also elsewhere on the board
LCD-RESET: RN4.8 (2); also elsewhere on the board
MAG-CS: RN7.2 (1); also elsewhere on the board
MAG-DRDY: RN8.4 (1); also elsewhere on the board
MAG-INT: RN8.1; also elsewhere on the board
unnamed: IC8.10 (!CS), RN7.7 (2)
unnamed: IC8.1 (SCL/SCLK), RN7.5 (2)
unnamed: IC8.11 (SDA/MOSI), RN7.6 (2)
unnamed: IC8.9 (SA1/MISO), RN7.8 (2)
unnamed: IC8.7 (INT), RN8.8 (2)
unnamed: IC8.8 (DRDY), RN8.5 (2)
unnamed: C29.1, IC8.4 (C1)
unnamed: C31.1, C32.1, IC8.5 (VDD), L4.1
unnamed: IC7.12 (INT), RN12.5 (2)
unnamed: C19.1, IC3.29 (VCC3.3), L1.1
unnamed: IC3.38 (RESET), RN4.1
unnamed: IC3.40 (LCD_ON), RN4.4 (1)
unnamed: IC3.1 (TP_IRQ), RN1.2 (1)
unnamed: IC3.39 (TP_CS), RN4.3 (1)
unnamed: IC3.5 (TP_CLK), RN1.4 (1)
unnamed: IC3.2 (TP_DOUT), RN1.1
unnamed: IC3.4 (TP_DIN), RN1.3 (1)
unnamed: RN2.7 (2), SD.8 (D1)
unnamed: RN2.8 (2), SD.7 (D0)
unnamed: RN3.5 (2), SD.5 (CLK)
unnamed: RN3.6 (2), SD.2 (CMD)
unnamed: RN3.8 (2), SD.9 (D2)
unnamed: RN3.7 (2), SD.1 (D3)
unnamed: RN2.6 (2), SD.CD
unnamed: RN2.5 (2), SD.WP
unnamed: C20.1, C21.1, IC2.5 (IN), L2.1
unnamed: IC6.1 (OUT), USB.1 (+5V)
unnamed: RN5.5 (2), USB.2 (D-)
unnamed: RN5.8 (2), USB.3 (D+)
unnamed: IC7.9 (AD0/SDO), RN12.8 (2)
unnamed: C25.1, IC7.10 (REGOUT)
unnamed: C27.1, C28.1, IC7.13 (VDD), L3.1
unnamed: IC7.24 (SDA/SDI), RN6.6 (2)
unnamed: IC7.23 (SCL/SCLK), RN6.7 (2)
unnamed: IC7.22 (!CS), RN6.8 (2)
OTG-FS-DM: RN5.4 (1); also elsewhere on the board
OTG-FS-DP: RN5.1; also elsewhere on the board
SD-CD: RN2.3 (1); also elsewhere on the board
SD-PWR: IC2.4 (EN), R3.1; also elsewhere on the board
SD-WP: RN2.4 (1); also elsewhere on the board
SDMMC1-CK: RN3.4 (1); also elsewhere on the board
SDMMC1-CMD: RN3.3 (1); also elsewhere on the board
SDMMC1-D0: RN2.1; also elsewhere on the board
SDMMC1-D1: RN2.2 (1); also elsewhere on the board
SDMMC1-D2: RN3.1; also elsewhere on the board
SDMMC1-D3: RN3.2 (1); also elsewhere on the board
SD_PWR: IC2.1 (OUT), SD.4 (VDD)
SPI4-MISO: RN1.8 (2), RN7.1, RN12.1; also elsewhere on the board
SPI4-MOSI: RN1.6 (2), RN6.3 (1), RN7.3 (1); also elsewhere on the board
SPI4-SCK: RN1.5 (2), RN6.2 (1), RN7.4 (1); also elsewhere on the board
TP-CS: RN4.6 (2); also elsewhere on the board
TP-IRQ: RN1.7 (2); also elsewhere on the board
USB-EN: IC6.4 (EN), R4.2; also elsewhere on the board

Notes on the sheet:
Design: A. Ryll
LCD
Microphones
SD Card
USB Host
Magnetometer
IMU


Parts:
ANT: ANT-SMARA; ANT-SMA-RA
C33: 0p5; C0402
C34, C36, C47, C49, C51: 100n; C0603
C35, C37, C48, C50, C52: 1n; C0603
C38: 100p; C0402
C39: 47p; C0402
C40: 0p8; C0402
C41: 1p5; C0402
C42, C44: NA; C0402
C43: 0p6; C0402
C45: 1u; C0603
C46, C53: 10n; C0603
C54, C55: 10u; C0603
IC9: SKY66112; SMCM-22
IC10: SX1280; QFN24L
IC11: LP5907MFX-3.3; SOT23-5L
L5, L6, L7: 120R; L0603
LED3: gr; CHIP-LED0603
Q2: FL520WFMT1; CRYSTAL-7M
R6: 3n; R0402
R7: 2n7; R0402
R8: 3n9; R0402
R9: 1k; R0603
RN9, RN10, RN11: 100; EXB28V

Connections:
+5V: L7.2; also elsewhere on the board
CPS: IC9.15 (CPS), RN11.5 (2)
CRX: IC9.2 (CRX), RN11.7 (2)
CTX: IC9.17 (CTX), RN11.8 (2)
GND: ANT.GND1 (GND), ANT.GND2 (GND), ANT.GND3 (GND), ANT.GND4 (GND), C34.2, C35.2, C36.2, C37.2, C40.2, C41.2, C42.2, C43.2, C44.2, C45.2, C46.2, C47.2, C48.2, C49.2, C50.2, C51.2, C52.2, C53.2, C54.2, C55.2, IC9.1 (GND), IC9.4 (ANT_SEL), IC9.5 (GND), IC9.7 (GND), IC9.9 (GND), IC9.10 (GND), IC9.12 (GND), IC9.13 (GND), IC9.18 (GND), IC9.20 (GND), IC9.22 (GND), IC9.PAD1 (GND), IC9.PAD2 (GND), IC10.5 (GND), IC10.13 (GND), IC10.20 (GND), IC10.21 (GND), IC10.23 (GND), IC10.24 (GND), IC10.PAD (GND), IC11.2 (GND), LED3.C, Q2.2 (GND1), Q2.4 (GND1), RN10.2 (1), RN10.3 (1), RN10.6 (2), RN10.7 (2); also elsewhere on the board
unnamed: LED3.A, R9.1
unnamed: C54.1, IC11.1 (VIN), L7.1
unnamed: IC10.17 (MOSI), RN9.8 (2)
unnamed: IC10.16 (MISO), RN9.7 (2)
unnamed: IC10.18 (SCK), RN9.6 (2)
unnamed: IC10.19 (!CS), RN9.5 (2)
unnamed: IC10.7 (BUSY), RN10.5 (2)
unnamed: IC10.8 (DIO1), RN10.8 (2)
unnamed: IC10.4 (XTB), Q2.3 (2)
unnamed: IC10.6 (XTA), Q2.1
unnamed: C45.1, C46.1, IC10.2 (VDD_IN), IC10.12 (DCC_FB)
unnamed: C53.1, IC10.1 (VR_PA)
unnamed: C38.2, IC9.21 (RFIN)
unnamed: C33.1, C41.1, R6.2, R7.1
unnamed: C33.2, C38.1, C42.1, R7.2
unnamed: C40.1, IC10.22 (RFIO), R6.1
unnamed: C39.1, IC9.8 (ANT1)
unnamed: C39.2, C43.1, R8.1
unnamed: ANT.C (1), C44.1, R8.2
SPI1-MISO: RN9.2 (1); also elsewhere on the board
SPI1-MOSI: RN9.1; also elsewhere on the board
SPI1-SCK: RN9.3 (1); also elsewhere on the board
WF-3V3: C55.1, IC11.5 (VOUT), L5.1, L6.1, R9.2
WF-BUSY: RN10.4 (1); also elsewhere on the board
WF-CPS: RN11.4 (1); also elsewhere on the board
WF-CRX: RN11.2 (1); also elsewhere on the board
WF-CS: RN9.4 (1); also elsewhere on the board
WF-CTX: RN11.1; also elsewhere on the board
WF-IRQ: RN10.1; also elsewhere on the board
WF-ON: IC11.3 (ON); also elsewhere on the board
WF_3V3FEM: C47.1, C48.1, C49.1, C50.1, C51.1, C52.1, IC9.3 (CSD), IC9.11 (VDD), IC9.14 (VCC2), IC9.16 (VCC1), IC9.19 (CHL), L6.2
WF_3V3SX: C34.1, C35.1, C36.1, C37.1, IC10.3 (!RESET), IC10.11 (V_DIO), IC10.15 (VBAT), L5.2

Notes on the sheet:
Design: A. Ryll
Wireless Interface


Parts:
C56, C58: 33u; C1206; VOLTAGE 25V
C57, C59: 100n; C0603
IC12: LT3080ST; SOT223
IDD: TE-FPC-1MM-8V; TE-1734248-8
L8: 470R; L1206
LED4: gr; CHIP-LED0603
LEDS: TE-FPC-1MM-10H; TE-1-84952-0
PAD1, PAD2, PAD3: WIREPAD5,4/3,0; 5,4/3,0
PWR: 4-1734742-0; TE-4-1734592-0
R10: 1k; R0603
R11: 330k; R0603
SW2: KT11P4SA3M; KT11

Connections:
+3V3: C58.1, IC12.2 (OUT), IC12.4 (OUT), R10.2; also elsewhere on the board
+5V: L8.1, LEDS.1, PWR.1, PWR.2; also elsewhere on the board
BTN: PWR.18, SW2.1
GND: C56.2, C57.2, C58.2, C59.2, LED4.C, LEDS.10, PAD1.1, PAD1.2, PAD2.1, PAD2.2, PAD3.1, PAD3.2, PWR.39, PWR.40, R11.1, SW2.2; also elsewhere on the board
IDD0: IDD.A2, IDD.B2; also elsewhere on the board
IDD1: IDD.A3, IDD.B3; also elsewhere on the board
IDD2: IDD.A4, IDD.B4; also elsewhere on the board
IDD3: IDD.A5, IDD.B5; also elsewhere on the board
IDD4: IDD.A6, IDD.B6; also elsewhere on the board
IDD5: IDD.A7, IDD.B7; also elsewhere on the board
IDD6: IDD.A8, IDD.B8; also elsewhere on the board
KICK-CHG: PWR.35; also elsewhere on the board
KICK-CS: PWR.31; also elsewhere on the board
KICK-ERR: PWR.38; also elsewhere on the board
KILL: PWR.17; also elsewhere on the board
unnamed: C59.1, IC12.1 (SET), R11.2
unnamed: LED4.A, R10.1
unnamed: C56.1, C57.1, IC12.3 (IN), L8.2
PDN: PWR.19; also elsewhere on the board
SMB-ALRT: PWR.13; also elsewhere on the board
SMB-RST: PWR.12; also elsewhere on the board
SMB-SCL: PWR.15; also elsewhere on the board
SMB-SDA: PWR.14; also elsewhere on the board
SPI2-MISO: PWR.33; also elsewhere on the board
SPI2-MOSI: PWR.32; also elsewhere on the board
SPI2-SCK: PWR.34; also elsewhere on the board
SRST: PWR.28; also elsewhere on the board
SWCLK: PWR.26; also elsewhere on the board
SWDIO: PWR.27; also elsewhere on the board
TIM1-CH1: PWR.16; also elsewhere on the board
TIM3-CH1: LEDS.2; also elsewhere on the board
TIM3-CH2: LEDS.3; also elsewhere on the board
TIM3-CH3: LEDS.4; also elsewhere on the board
TIM3-CH4: LEDS.5; also elsewhere on the board
TIM4-CH1: LEDS.6; also elsewhere on the board
TIM4-CH2: LEDS.7; also elsewhere on the board
TIM4-CH3: LEDS.8; also elsewhere on the board
TIM4-CH4: LEDS.9; also elsewhere on the board
TIM13-CH1: PWR.36; also elsewhere on the board
TIM14-CH1: PWR.37; also elsewhere on the board
UART4-RX: PWR.9; also elsewhere on the board
UART4-TX: PWR.10; also elsewhere on the board
UART5-RX: PWR.5; also elsewhere on the board
UART5-TX: PWR.6; also elsewhere on the board
UART7-RX: PWR.7; also elsewhere on the board
UART7-TX: PWR.8; also elsewhere on the board
UART8-RX: PWR.3; also elsewhere on the board
UART8-TX: PWR.4; also elsewhere on the board
USART1-RX: PWR.30; also elsewhere on the board
USART1-TX: PWR.29; also elsewhere on the board
USART2-RX: PWR.23; also elsewhere on the board
USART2-TX: PWR.22; also elsewhere on the board
USART3-RX: PWR.21; also elsewhere on the board
USART3-TX: PWR.20; also elsewhere on the board
USART6-RX: PWR.24; also elsewhere on the board
USART6-TX: PWR.25; also elsewhere on the board
USB-ATT: PWR.11; also elsewhere on the board

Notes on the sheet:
LDO 3.3V
Design: A. Ryll
Connectors



Board: 4 copper layers, 80.0 x 85.0 mm, 118 parts (3 on the bottom side), 181 nets.

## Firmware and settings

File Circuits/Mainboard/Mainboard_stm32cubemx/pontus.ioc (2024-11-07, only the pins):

Mcu.UserName=STM32H723ZGTx
PA0.GPIO_Label=M1_PWM
PA0.Signal=S_TIM5_CH1
PA1.GPIO_Label=M1_Encoder_B
PA1.Signal=S_TIM2_CH2
PA10.GPIO_Label=USB_FS_ID
PA10.Signal=USB_OTG_HS_ID
PA11.GPIO_Label=USB_FS_DM
PA11.Signal=USB_OTG_HS_DM
PA12.GPIO_Label=USB_FS_DP
PA12.Signal=USB_OTG_HS_DP
PA13(JTMS/SWDIO).GPIO_Label=SWDIO
PA13(JTMS/SWDIO).Signal=DEBUG_JTMS-SWDIO
PA14(JTCK/SWCLK).GPIO_Label=SWCLK
PA14(JTCK/SWCLK).Signal=DEBUG_JTCK-SWCLK
PA15(JTDI).GPIO_Label=M1_Encoder_A
PA15(JTDI).Signal=S_TIM2_CH1_ETR
PA2.GPIO_Label=M2_TX
PA2.Signal=USART2_TX
PA3.GPIO_Label=M2_RX
PA3.Signal=USART2_RX
PA4.GPIO_Label=WSENS_CS
PA4.Signal=GPIO_Output
PA5.GPIO_Label=WSENS_SCL
PA5.Signal=SPI1_SCK
PA6.GPIO_Label=WSENS_SAO
PA6.Signal=SPI1_MISO
PA7.GPIO_Label=RMII_CRS_DV
PA7.Signal=ETH_CRS_DV
PA8.GPIO_Label=VL6180_SCL
PA8.Signal=I2C3_SCL
PA9.GPIO_Label=USB_FS_VBUS
PA9.Signal=USB_OTG_HS_VBUS
PB0.GPIO_Label=LED_GREEN
PB0.Signal=GPIO_Output
PB10.GPIO_Label=VL53L4CD_SCL
PB10.Signal=I2C2_SCL
PB11.GPIO_Label=VL53L4CD_SDA
PB11.Signal=I2C2_SDA
PB12.GPIO_Label=Rpi_RX
PB12.Signal=UART5_RX
PB13.GPIO_Label=RMII_TXD1
PB13.Signal=ETH_TXD1
PB14.GPIO_Label=M5_PWM
PB14.Signal=S_TIM12_CH1
PB15.GPIO_Label=M1_RX
PB15.Signal=USART1_RX
PB3(JTDO/TRACESWO).GPIO_Label=SWO
PB3(JTDO/TRACESWO).Signal=DEBUG_JTDO-SWO
PB4(NJTRST).GPIO_Label=M2_Encoder_A
PB4(NJTRST).Signal=S_TIM3_CH1
PB5.GPIO_Label=M2_Encoder_B
PB5.Signal=S_TIM3_CH2
PB6.GPIO_Label=M1_TX
PB6.Signal=USART1_TX
PB7.GPIO_Label=M3_Encoder_B
PB7.Signal=S_TIM4_CH2
PB8.GPIO_Label=SEN0374_SCL
PB8.Signal=I2C1_SCL
PB9.GPIO_Label=SEN0374_SDA
PB9.Signal=I2C1_SDA
PC1.GPIO_Label=RMII_MDC
PC1.Signal=ETH_MDC
PC10.GPIO_Label=M5_TX
PC10.Signal=UART4_TX
PC11.GPIO_Label=M5_RX
PC11.Signal=UART4_RX
PC12.GPIO_Label=Rpi_TX
PC12.Signal=UART5_TX
PC13.GPIO_Label=B1 (Blue_User_Button)
PC13.Signal=GPIO_Input
PC14-OSC32_IN.Signal=RCC_OSC32_IN
PC15-OSC32_OUT.Signal=RCC_OSC32_OUT
PC2_C.GPIO_Label=RF_MISO
PC2_C.Signal=SPI2_MISO
PC3_C.GPIO_Label=RF_MOSI
PC3_C.Signal=SPI2_MOSI
PC4.GPIO_Label=RMII_RXD0
PC4.Signal=ETH_RXD0
PC5.GPIO_Label=RMII_RXD1
PC5.Signal=ETH_RXD1
PC6.GPIO_Label=M4_Encoder_A
PC6.Signal=S_TIM8_CH1
PC7.GPIO_Label=M4_Encoder_B
PC7.Signal=S_TIM8_CH2
PC8.GPIO_Label=VL6180_IO0
PC8.Signal=GPIO_Output
PC9.GPIO_Label=VL6180_SDA
PC9.Signal=I2C3_SDA
PD10.Signal=GPIO_Output
PD12.GPIO_Label=M3_Encoder_A
PD12.Signal=S_TIM4_CH1
PD13.GPIO_Label=SEN0374_INT
PD13.Signal=GPIO_Output
PD14.GPIO_Label=SEN0374_Boot
PD14.Signal=GPIO_Output
PD15.GPIO_Label=SEN0374_PS1
PD15.Signal=GPIO_Output
PD3.GPIO_Label=RF_SCK
PD3.Signal=SPI2_SCK
PD7.GPIO_Label=WSENS_SDA
PD7.Signal=SPI1_MOSI
PD8.GPIO_Label=STLK_VCP_RX
PD8.Signal=USART3_TX
PD9.GPIO_Label=STLK_VCP_TX
PD9.Signal=USART3_RX
PE1.GPIO_Label=LED_YELLOW
PE1.Signal=GPIO_Output
PE15.GPIO_Label=RF_CS
PE15.Signal=GPIO_Output
PE2.GPIO_Label=M4_RX
PE2.Signal=USART10_RX
PE3.GPIO_Label=M4_TX
PE3.Signal=USART10_TX
PE5.GPIO_Label=M2_PWM
PE5.Signal=S_TIM15_CH1
PF0.GPIO_Label=VL53L4CD2_SDA
PF0.Signal=I2C5_SDA
PF1.GPIO_Label=VL53L4CD2_SCL
PF1.Signal=I2C5_SCL
PF11.GPIO_Label=M4_PWM
PF11.Signal=TIM24_CH1
PF14.GPIO_Label=ADPS-9960_SCL
PF14.Signal=I2C4_SCL
PF15.GPIO_Label=ADPS-9960_SDA
PF15.Signal=I2C4_SDA
PF2.GPIO_Label=VL53L4CD_SHUT
PF2.Signal=GPIO_Output
PF3.GPIO_Label=VL53L4CD_INT
PF3.Signal=GPIO_Output
PF4.GPIO_Label=VL53L4CD2_INT
PF4.Signal=GPIO_Output
PF5.GPIO_Label=VL53L4CD2_SHUT
PF5.Signal=GPIO_Output
PF6.GPIO_Label=M3_PWM
PF6.Signal=TIM23_CH1
PG11.GPIO_Label=RMII_TX_EN
PG11.Signal=ETH_TX_EN
PG13.GPIO_Label=RMII_TXD0
PG13.Signal=ETH_TXD0
PG14.GPIO_Label=M3_TX
PG14.Signal=USART6_TX
PG2.GPIO_Label=SEN0374_PS2
PG2.Signal=GPIO_Output
PG3.GPIO_Label=SEN0374_BL-IND
PG3.Signal=GPIO_Output
PG4.GPIO_Label=SEN0374_RST
PG4.Signal=GPIO_Output
PG5.Signal=GPIO_Output
PG6.GPIO_Label=ADPS-9960_INT
PG6.Signal=GPIO_Output
PG7.GPIO_Label=USB_FS_OVCR
PG7.Signal=GPXTI7
PG8.GPIO_Label=VL6180_IO1
PG8.Signal=GPIO_Output
PG9.GPIO_Label=M3_RX
PG9.Signal=USART6_RX
PH0-OSC_IN.GPIO_Label=MCO
PH0-OSC_IN.Signal=RCC_OSC_IN
PH1-OSC_OUT.Signal=RCC_OSC_OUT

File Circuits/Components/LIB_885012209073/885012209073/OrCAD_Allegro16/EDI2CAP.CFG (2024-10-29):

;>------- Configuration parameters: -------<
;>------Check EDIF2CAP.PDF for details ----<

[OrCAD Writer]

SuppressWarnings = 0	
ConvertOnlyLibs = 0
UnitMeasurement = default
PinToPin = 0
Grid = 0
EnableOffgridObjects = 0
GenerateIniFile = 1
OrcadConventions = 1
UseDesignatorsForPackaging = 1
DesignatorsEndOnLetters = 0
DesignatorsSameInHierarchy = 1
GeneratePinNumbers = 0
GeneratePortSymbols = 1
GenerateOffPageConnectors = 0
GenerationVisible = 1
CaptureLibsWithUserPackages = ""
SystemNetNamePrefix = ""
BackgroundTextScale = 0.8
DefaultNetNameScale = 0.3
StandardPageSize = 0
EliminatePageText = 0
SmashTitleBlock = 0
PinDisplayStyle = orcad
TopView = ""
ComponentsMode = 0
ReplacePartWithNoPinsWithTitleBlock = 0
ChangeBusBaseThatEndsOnDigit = 0
ProcessBackAnnotation = 1

[Mapper]

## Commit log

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2024-09-19 Created a BOM for break beam, IMU, encoders, obsticle detection and communication. It is far from finished but you could add your area responsibilities.
    [RoboCUP_SSL_Hardware_BOM.xlsx]
2024-09-19 added an object detection sensor that we could use.
    [RoboCUP_SSL_Hardware_BOM.xlsx]
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2024-09-23 Received answers from a retailer so I updated the price for an encoder as well as added a sensor for vision outwards.
    [RoboCUP_SSL_Hardware_BOM.xlsx]
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2024-09-23 Added two break beam sensors, one with a 5mm beam and one with a 3mm beam. A 5mm beam is a bit more robust and that might be important since there most likely will be some collision with other robots.
    [RoboCUP_SSL_Hardware_BOM.xlsx]
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2024-09-24 Changed communication column since the ESP32 supports Wifi there is no need for additional communication hardware.
    [RoboCUP_SSL_Hardware_BOM.xlsx]
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2024-09-24 Added a few comments and addtional hardware to the BOM. After speaking with Emil it was suggested that it would be beneficial to make sure that the camera and the microcontroller support each other.
    [RoboCUP_SSL_Hardware_BOM.xlsx]
2024-09-24 Finished the BOM for communication and sensors. Added the last obsticle detection sensor, an ESP32-CAM which includes a camera as well as a development board.
    [RoboCUP_SSL_Hardware_BOM.xlsx]
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2024-09-25 Added a few comments and additional retailers based on the feedback we reveived from Henrik Falk.
    [BOM.xlsx]
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2024-09-26 Updated a few of the links to the retailer website. One based on the feedback given by Henrik on preferred retailers and another since the previous was not up to date. I also added a sheet with the v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
    [BOM.xlsx]
2024-09-26 Created a folder for voltage distribution however, since I have never used KiCad before I created a folder and project called 'youtube tutorial learn KiCad in 8 minutes'. Once I feel that I have lear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
    [youtube tutorial learn KiCad in 8 minutes.kicad_pcb, youtube tutorial learn KiCad in 8 minutes.kicad_sch]
2024-09-26 Added a circuit and made some small changes in the kicker circuit
    [CapacitorChargerCircuit_v0.1.kicad_sch, CapacitorChargerTestCircuit.kicad_sch]
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2024-09-27 Created folders for the buck converters that will be created. We need to have buck converters from 24V to 3.3, 5, 12, and 15V.
    [Voltage distribution from 24V to 3V.kicad_pcb, Voltage distribution from 24V to 3V.kicad_sch]
2024-09-27 Changed the organisation of the excel files. Instead of having the voltage of the sensors as a sheet in BOM.xlsx I created a new excel file with the same information and put the file in Circuits/Volt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
    [BOM.xlsx, Different voltage levels summary.xlsx]
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2024-10-01 Updated the obsticle detection sensor section with up to date links and prices. Also promoted that the Raspberry Pi 4 Model B/8GB is the one we would like so that we can run both object detection as 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
    [BOM.xlsx]
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2024-10-04 Added the break beam sensor that has been lost. I also included comments to the prices that I know include moms.
    [BOM.xlsx]
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2024-10-10 Added alternative motor driver B-G431B-ESC1, Nucleo 144 Dev board as alternative to ESP32, RF tranceivers that are proven to be reliable for communication with server laptop
    [BOM.xlsx]
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2024-10-10 Changed ranking of the wheel encoders and calculated sum for 1 robot
    [BOM.xlsx]
2024-10-11 Updated the BOM and created a folder for encoder IC for the AEDB-9140-A13.
    [BOM.xlsx, BROADCOM AEDB-9140-A13.kicad_pcb, BROADCOM AEDB-9140-A13.kicad_sch]
2024-10-11 Added a folder called 'Encoder circuits' with an IC schematic for how the optical encoder AEDB-9140-A13 should be connected according to its datasheet.
    [BROADCOM AEDB-9140-A13.kicad_sch]
2024-10-11 Added a directory called 'IMU Circuit' in 'Circuits' directory. Also started the IC for the IMU.
    [WSEN-ISDS 6 Axis IMU - Circuit.kicad_pcb, WSEN-ISDS 6 Axis IMU - Circuit.kicad_sch]
2024-10-12 Added kicker components to the excel BOM file, exported all components to a csv file to streamline adding components and avoiding merge conflicts. Please use the CSV file to add your components
    [BOM.xlsx, BOM_Copy.csv]
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2024-10-14 BOM.csv: Added reverse polarity protection component
    [BOM.csv]
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2024-10-14 BOM_wurth.csv: Added components we want to order from wurth, 10 decoupling capacitors
    [BOM_wurth.csv]
2024-10-14 BOM.csv: Added components for reverse voltage protection circuit
    [BOM.csv]
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2024-10-15 Main.tex: Added alternative BOM and replacement components
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2024-10-17 BOM.csv: Added all components that was approved to order, added a 9Dof BNO055 IMU
    [BOM.csv]
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2024-10-17 added pillow blocks for the wheels, updated bearings and amount of bearings.
    [BOM.csv]
2024-10-17 BOM.csv: Merged, ordered components by seller, updated prices on components from elefun
    [BOM.csv]
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2024-10-17 Created pdf for the bom we are to order and moved udebom
    [UdeA_BOM.xlsx]
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2024-10-17 Mainboard: Placed connectors and reverse protection components
    [Mainboard.kicad_sch]
2024-10-17 removed flanged bearings while awaiting cost proposal and fixed pillow block link
    [BOM.csv]
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2024-10-17 Fixed pillow block link again
    [BOM.csv]
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2024-10-17 Added all ORing components and reverse voltage protection components
    [Mainboard.kicad_pcb, Mainboard.kicad_sch]
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2024-10-17 BOM_wurth.csv: Added Socket headers and pin headers and resistors and added footprint in the description
    [BOM_wurth.csv]
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2024-10-18 Removed unused components and added the rest of the nucleo to kicad schematic
    [Mainboard.kicad_pcb, Mainboard.kicad_sch, STMicroelectronics_-_B-G431B-ESC1.step]
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2024-10-27 Removed wrong datasheet for motor driver
2024-10-27 Do not track mainboard.step since it is too large
2024-10-27 Removed cached mainboard.step since it is too large
    [Mainboard.step]
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2024-10-28 Removed components from the pcb to make it easier to work with
    [Mainboard.kicad_pcb, Mainboard.kicad_sch, Mainboard.step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]
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2024-11-13 Updated the capacitor footprints to 0805, since everyone was different. Added powerplane and groundplane, vias for ground connections, added a connector to for the solenoid to a 1x2 pin headers since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
    [Kicker_Control_Circuit.kicad_pcb, Kicker_Control_Circuit.kicad_sch]
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

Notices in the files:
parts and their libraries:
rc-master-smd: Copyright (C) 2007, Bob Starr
